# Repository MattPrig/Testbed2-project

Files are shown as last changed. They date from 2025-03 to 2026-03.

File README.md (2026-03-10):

# 🤖 Variable Mechanical Stiffness Robotics Arm - Testbed 2

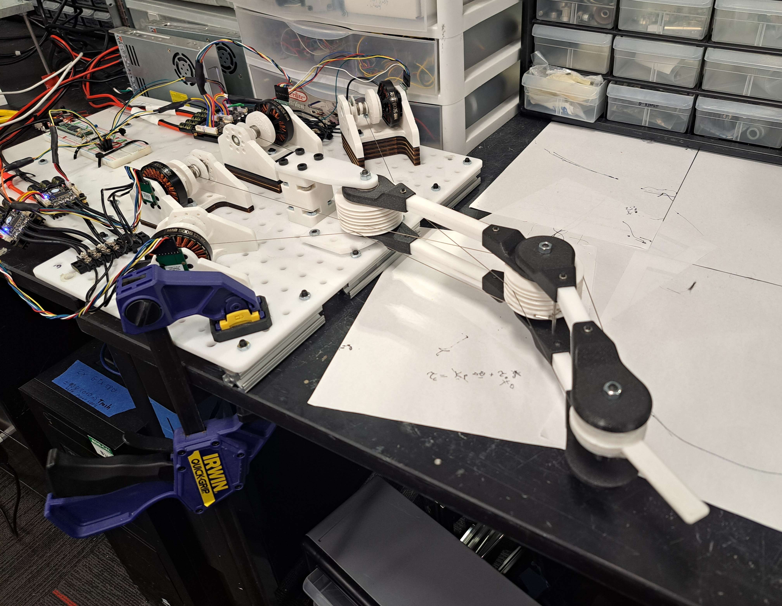
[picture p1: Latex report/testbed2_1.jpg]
Testbed Overview


## 🌟 Overview
This repository documents the development, construction, and testing of **Testbed 2**, a variable mechanical stiffness robotic arm. Built by **Matthieu Prigent** during it's internship in Salisbury Robotic Lab at Stanford, this prototype serves as a learning platform for the development of tendon-driven actuation and variable impedance control.

> [!NOTE]
> For a comprehensive technical analysis, please refer to the [Testbed 2 report.pdf](./Testbed%202%20report.pdf) located in the project root.

---

## 🛠️ System Architecture

### 🦴 Mechanical Design
The arm features a **tendon-driven system** with 3 joints controlled by 4 motors.
- **Cable Routing**: Designed for high symmetry to simplify control implementation.
- **Construction**: 3D printed PLA, lasercut Delrin, and Plexiglas.
- **Pulleys**: Sized to achieve a target force of ~16N at the end effector.
- **Interactive CAD**: The Onshape model can be accessed [here](https://cad.onshape.com/documents/c940a6fae7dfa620c9d885fc/w/fe90fad0bb4f54c2b765f4a7/e/dd32a71d364b7df9178d1a8b).

### ⚡ Electronics
A robust electronic backbone ensures high-speed control and communication:
- **MCU**: [Teensy 4.1](https://www.pjrc.com/store/teensy41.html) (Master controller).
- **Motor Drivers**: FLIPSKY Mini FSESC6.7 PRO (modified with $0.05\Omega$ resistors).
- **Motors**: 5008 EEE 170kV MAD brushless motors.
- **Sensors**: AS5048A magnetic absolute encoders.
- **Bus**: CAN bus for master-slave communication.

### 💻 Software Stack
- **Framework**: PlatformIO on VSCode.
- **Real-time Logic**: Based on the `TaskScheduler` library for deterministic execution.
- **FOC Control**: Utilizes the [SimpleFOC](https://docs.simplefoc.com/) library for precise torque and position control.
- **PC Interface**: Python-based GUI for real-time monitoring and control.

---

## 🕹️ Control Strategies

### 1. Torque Control
Implemented with a **coactivation** principle to maintain cable tension even when zero net torque is applied to the joints.

### 2. Position Control
A PD control loop in the joint space ($\theta$ space), allowing for stiff or compliant behavior by tuning $K_p$ and $K_d$ values.

### 3. Cartesian Control
Inverse kinematics implemented for the first two joints, allowing the end effector to follow lines or reach specific points in a 2D plane.

---

## 🔬 Anticogging Project
A specialized effort was made to mitigate **cogging torque**—the parasitic magnetic friction in brushless motors.
- **Status**: Captured cogging patterns using Fourier analysis (identifying 14Hz and 112Hz harmonics).
- **Location**: See the `anticogging project` directory for data collection scripts and analysis.

---

## 📂 Repository Structure
```text
.
├── anticogging project   # Scripts and data for cogging mitigation
├── Latex report         # Source files and images for the technical report
├── Testbed 2 report.pdf  # Final compiled report
└── Testbed2 code         # Source code for Teensy and Motor Drivers
    ├── Drivers code      # SimpleFOC implementation for drivers
    ├── Positioncontrolmaster # Teensy code for position control
    └── Torquecontrolmaster   # Teensy code for torque control
```

---

## 🚀 Future Improvements for Testbed 3
- [ ] **Structural Rigidity**: Link the top and bottom of the arm; use aluminum for load-bearing parts.
- [ ] **Cable Management**: Switch to spiral drums and Dyneema cables to reduce wear.
- [ ] **Electronics**: Switch to ODrive S1 drivers for native anticogging and better reliability.
- [ ] **Automation**: Fully implement absolute encoder sensing for the anticogging startup.

---
**Author**: Matthieu Prigent  
**Contact**: [matthieu.prigent@student-cs.fr](mailto:matthieu.prigent@student-cs.fr)

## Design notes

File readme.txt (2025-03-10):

This repo is to be used on the Testbed 2 prototype of the variable impedance actuator project.

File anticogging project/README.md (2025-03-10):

This whole project was to try to implement an anticogging feature to a brushless motor, to be used in robotic actuation with low gear reduction ratio.
It's still a bit messy as the data needs by hand post-processing, but the idea is to collect datas on currents used by the motor at every angle, use these datas to generate a lookup table of the compensation needed for cogging, and then use this lookup table of course.
I tried two current sensing methods, one measuring the direct DC current into the system at every angle, and another using the "virtual" Qcurrent from Field-Oriented Control processing.

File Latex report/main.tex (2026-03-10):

\documentclass{article}

% Language setting
% Replace `english' with e.g. `spanish' to change the document language
\usepackage[english]{babel}

% Set page size and margins
% Replace `letterpaper' with `a4paper' for UK/EU standard size
\usepackage[letterpaper,top=2cm,bottom=2cm,left=3cm,right=3cm,marginparwidth=1.75cm]{geometry}

% Useful packages
\usepackage{amsmath}
\usepackage{graphicx}
\usepackage{textalpha}
\usepackage{float}
\usepackage[colorlinks=true, allcolors=blue]{hyperref}

\title{Variable mechanical stiffness robotics arm testbed}
\author{Matthieu Prigent}

\begin{document}
\maketitle

\begin{abstract}
This document aims to summarize what was done in the development and building of testbed 2, and what was learned from it, for further development with testbed 3.
\end{abstract}

\begin{figure}[H]
\centering

\end{figure}

\newpage
\tableofcontents
\newpage

\section{Introduction}

This document aims to summarize what was done in the development and building of testbed 2, and what was learned from it, for further development with testbed 3. All of the documents related with this report, which include the software for running the arm and the can be found on this git repo and this drive. The Onshape model can be found \href{https://cad.onshape.com/documents/c940a6fae7dfa620c9d885fc/w/fe90fad0bb4f54c2b765f4a7/e/dd32a71d364b7df9178d1a8b}{here}.

\begin{figure}[H]
\centering
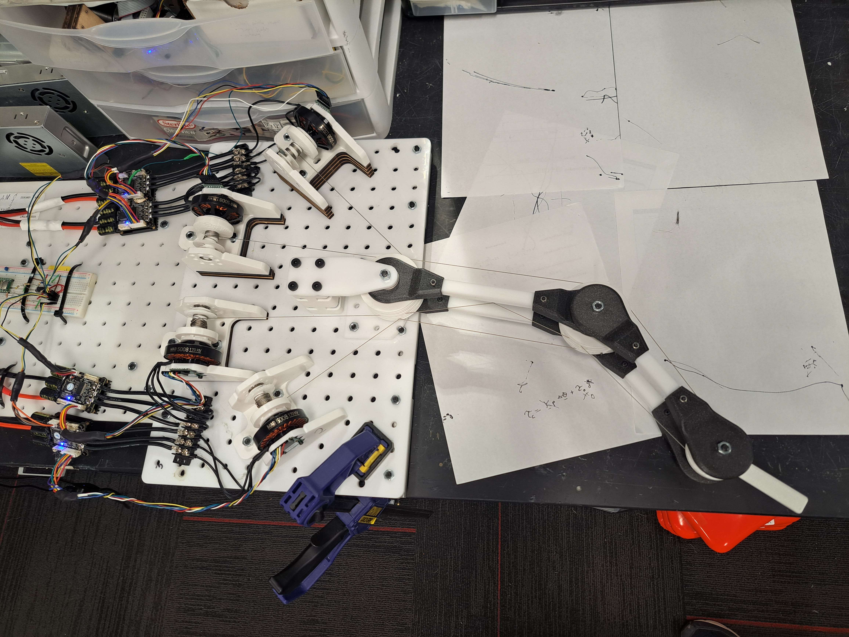
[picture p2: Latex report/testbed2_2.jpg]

\caption{\label{fig:overview}Overview of the testbed.}
\end{figure}

On the previous figure \ref{fig:overview}, we can see the testbed, with the main micro controller (partially cut on it) on  the far left, then the 4 motor drivers linked throught the CAN bus, the 4 motor pods, and then the arm with its 3 joints.

\section{Mechanical design}

\subsection{cable routing}

\begin{figure}[H]
\centering
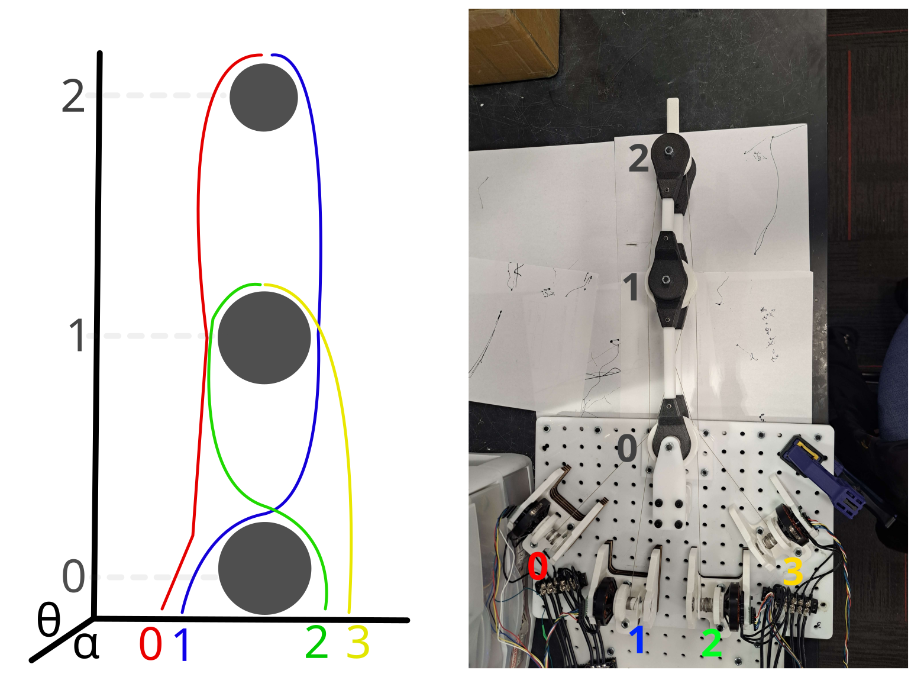
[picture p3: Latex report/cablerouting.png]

\caption{\label{fig:cablerouting}Routing of the cables in the arm.}
\end{figure}

The routing of the cables is done as shown on \ref{fig:cablerouting}. This geometry was choose for it's high degree of symmetry and hence easier control implementation features. We call the angle of each of the motors that are pulling a cable \textalpha, going from 0 to 3. We call the angle of each of the joints from the arm \texttheta, going from 0 to 2. On the actual arm, the cable linked to the motor 0 is on the top pulleys, while the cable linked to the motor 3 is on the bottom pulley. Based on \ref{fig:cablerouting}, we get that the matrix of the direction of the arm, going from \textalpha to \texttheta, is :

\begin{align}
P_{0} = \begin{pmatrix}
1 & 1 & -1 & -1 \\
1 & -1 & 1 & -1 \\
1 & -1 & 0 & 0 
\end{pmatrix}
\end{align}

Now, taking into account the diameter of the pulleys, calling $d_{m}$ the diameter of the motor pulleys and $D_{0}$, $D_{1}$ and $D_{2}$ the respective diameter of the 3 joints, we can rewrite the matrix while taking into account the reduction ratio :

\begin{align}
P = d_m \begin{pmatrix}
\frac{1}{D_{0}} & \frac{1}{D_{0}}  & -\frac{1}{D_{0}}  & -\frac{1}{D_{0}}  \\
\frac{1}{D_{1}} & -\frac{1}{D_{1}} & \frac{1}{D_{1}} & -\frac{1}{D_{1}} \\
\frac{1}{D_{2}} & -\frac{1}{D_{2}} & 0 & 0 
\end{pmatrix}
\end{align}

\subsection{sizing of the arm}

\begin{figure}[H]
\centering
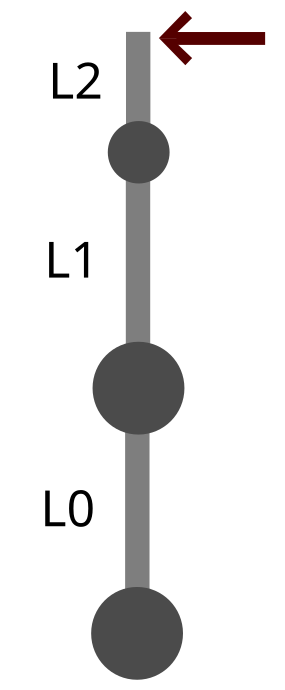
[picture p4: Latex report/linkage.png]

\caption{\label{fig:linkage}Size of the different links of the arm, and direction of the desired force capability of the arm.}
\end{figure}

To get a certain area for the arm the be able to reach, we arbitrary choose the length of the links so that the arm is about ~45cm long. We will name the length of the links $L_{0}$, $L_{1}$ and $L_{2}$. get a certain force capability $F$ at the output of the arm, we need to size the pulleys accordingly, knowing the defined length. We will name the torque capabilities of each joint $\tau_{0}$, $\tau_{1}$ and $\tau_{2}$. Finally, the torque of the motors will be named $\tau_{mi}$.
\\
First, we can write relation between $\tau_{mi}$ and the $\tau_{i}$.

\begin{align}
\frac{1}{d_{m}}
\begin{pmatrix}
D_{0} & D_{0} & -D_{0} & -D_{0}\\
0 & 0 & D_{1} & -D_{1}\\
D_{2} & -D_{2} & 0 & 0\\
\end{pmatrix}
\begin{pmatrix}
\tau_{m0} \\
\tau_{m1} \\
\tau_{m2} \\
\tau_{m3}
\end{pmatrix}
=\begin{pmatrix}
\tau_{0} \\
\tau_{1} \\
\tau_{2}
\end{pmatrix}
\end{align}

We can see a major difference between this matrix and the kinematics matrix seen above, which is that the motors 0 and 1 do moves when the second joint is rotated, but do not contribute to the torque on the second joint. This result is quiet unintuitive, but can be verified experimentally on the testbed.
To get the maximum torque of each joint, we use this relation and specify that the motors pulling in the desired direction are at $\tau_{mmax}$, and the ones from the other side are at the base co-activation $\tau_{mmin}$.

\begin{align}
\frac{2D_0}{d_m}(\tau_{mmax}-\tau_{mmin}) = \tau_{0} \\
\frac{D_1}{d_m}(\tau_{mmax}-\tau_{mmin}) = \tau_{1} \\
\frac{D_2}{d_m}(\tau_{mmax}-\tau_{mmin}) = \tau_{2}
\end{align}

Which, making the hypothesis that the co-activation is small compared to $\tau_{mmax}$ get us to :

\begin{align}
\frac{2D_0\tau_{mmax}}{d_m} = \tau_{0} \\
\frac{D_1\tau_{mmax}}{d_m} = \tau_{1} \\
\frac{D_2\tau_{mmax}}{d_m} = \tau_{2}
\end{align}

We need, if we desire to keep the arm in an equilibrium, to verify 

\begin{align}
F = \frac{\tau_{2}}{L_{2}} = \frac{\tau_{1}}{L_{2}+L_{1}} = \frac{\tau_{0}}{L_{2}+L_{1}+L_{0}}
\end{align}

Combining these equations and the precedent reasoning on the arm, we finally get that the diameters of the pulleys must verify :

\begin{align}
D_2 &= \frac{F d_mL_{2}}{ \tau_{mmax}} \\
D_1 &= \frac{F d_m(L_{2}+L_{1})}{ \tau_{mmax}} \\
D_0 &= \frac{F d_m(L_{2}+L_{1}+L_{0})}{2 \tau_{mmax}}
\end{align}

And we see that all of the 3 pulleys are proportional to the diameter of the motor pulleys. The motor pulleys diameter can be choose arbitrarily, but its final value will change the tension of the cables. Bigger motor pulleys will mean relieving the cables from some stress, but also that the value of the $D_{i}$ will be bigger, which can be inconvenient for the size of the arm. The final choice was to made these pulley quiet small.

\vspace{0.5cm}
Now we know that $\tau_{mmax}$ is about 1N.m for a motor, that $L_0=21cm$, $L_1=16cm$, $L_2=9cm$ and that $d_m=1.4cm$.
The target force that we want is about 16N of force. We could go for a bigger force and hence reduction ratio, but that would lead to a high refleted inertia of the motor to the arm). With all of that, we get that $D_2 = 2cm$, $D_1=5.6cm$ and $D_0=5.2cm$. These value were in the end rounded to $D_2 = 3cm$, $D_1=6cm$ and $D_0=6cm$, ensuring that we get the desired force capability.

\subsection{Building of the testbed}
The testbed was designed entirely on Onshape, the project can be found \href{https://cad.onshape.com/documents/c940a6fae7dfa620c9d885fc/w/fe90fad0bb4f54c2b765f4a7/e/dd32a71d364b7df9178d1a8b}{here}.
The testbed was build using mostly 3D printed PLA, and lasercutting of Delrin and Plexiglas for some parts (using the laser cutter from lab64). This was because of the convenience of using already mastered tools for me, instead of going for more rigid aluminum. I would say it's fine for what we are doing with this testbed right now.

\begin{figure}[H]
\centering
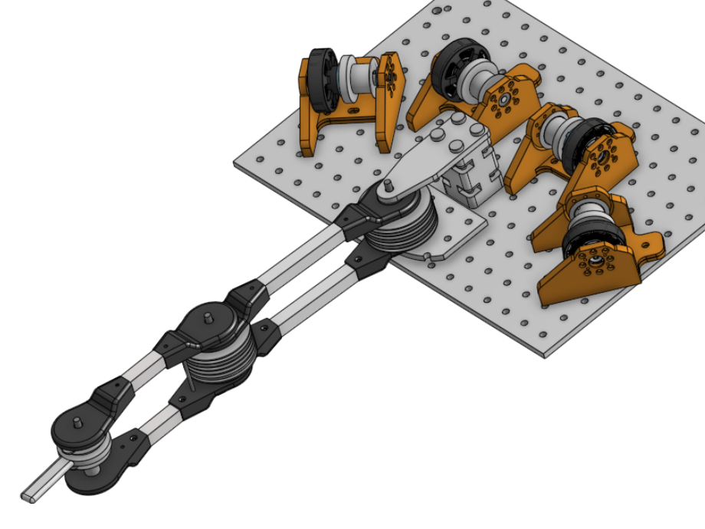
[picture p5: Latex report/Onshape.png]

\caption{\label{fig:Onshape}Onshape model.}
\end{figure}

\subsection{What to improve mechanically for testbed 3}

\begin{itemize}
\item Design a structural link between the top and the bottom part of the arm to improve it's rigidity by a lot (see the blue lines on \ref{fig:pulleysideview}).
\item Switch to aluminum for parts that handle a lot of load and can bend due to it (You can use sendcutsend or JLCCNC for machining them if necessary, it is not that expensive if the part is designed properly). Some of the parts that were bending a lot were especially on the motor side, like the main plate that was made out of flexible Plexiglas, and the motor pulley as well. For the motor pulley, putting a Dowel pin in it may do the trick for making it more rigid.
\item Switch to a spiral drum and spiral pulleys to prevent cables from ripping against each other. The current smooth pulleys and drums lead to some undesired behaviors, long term tear off of the cable and awful noises. This may be a not so good idea if the arm pulleys ends up being taller, making the arm too tall compared to its width.
\item switch from steel cables to dyneema cable.
\item We can merge two of the pulleys from the second joint (the ones circled in red on \ref{fig:pulleysideview}) into one, as their movement are already linked anyway. This reduce the part count and complexity of the arm by a bit. What to get from this is that one pulley per cable is not necessary if adjacent pulleys ends up having a linked rotation in the same direction anyway.
\end{itemize}

The next mechanical challenges to solve on testbed 3 nest in how to run the cables in a non-planar arm.

\begin{figure}[H]
\centering
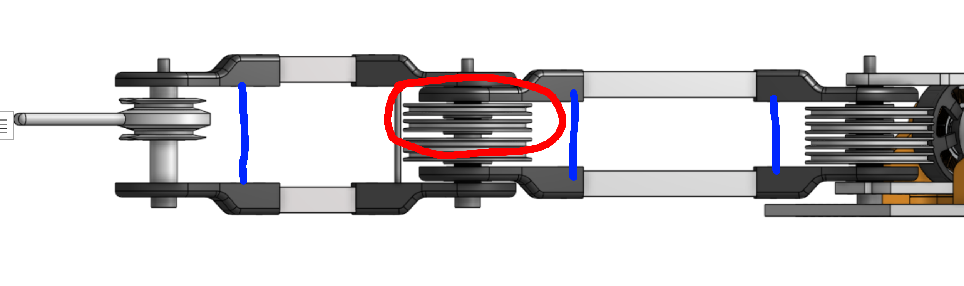
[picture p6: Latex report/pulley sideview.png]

\caption{\label{fig:pulleysideview}Sideview of the arm on Onshape.}
\end{figure}

\begin{figure}[H]
\centering
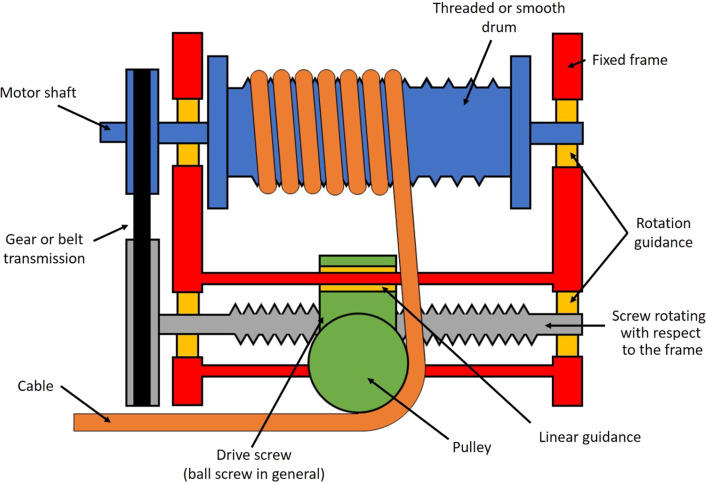
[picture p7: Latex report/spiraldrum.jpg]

\caption{\label{fig:spiraldrum}An example of an interesting way to make a spiral drum. Doing it this way can also enable a permanent pretensioning of the cables by adding a spring in the system.}
\end{figure}

\section{Electrical design}

\subsection{General architecture}

\begin{figure}[H]
\centering
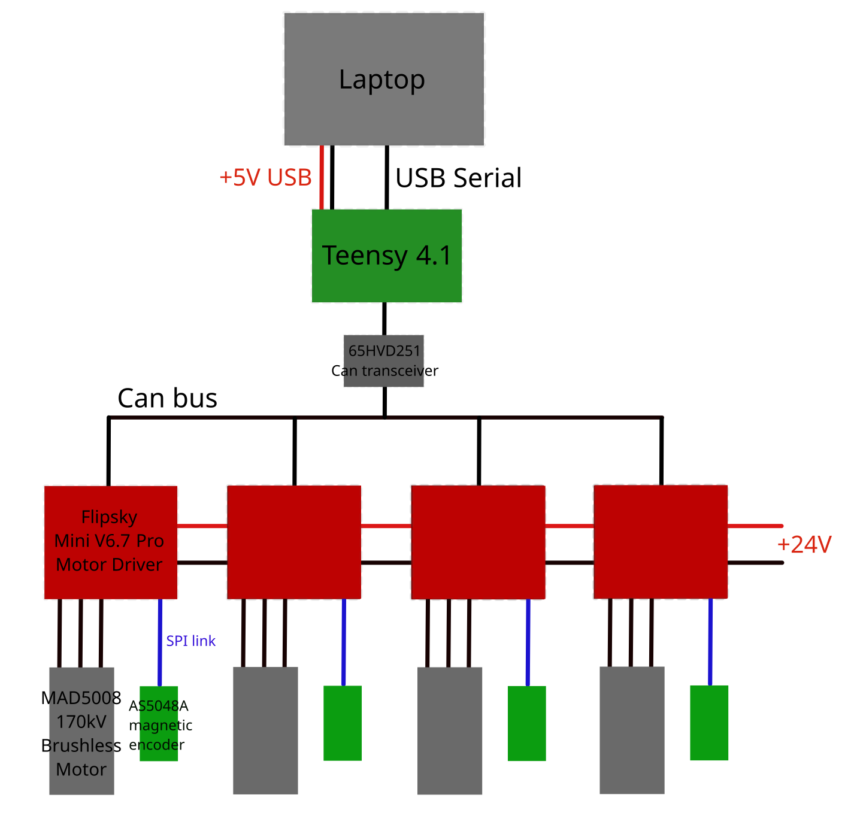
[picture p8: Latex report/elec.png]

\caption{\label{fig:elec}Architecture of the electronics of the arm.}
\end{figure}

To power on the testbed, you need to plug in the two 24V power supplies that power the motor drivers, and then plug in the usb cable coming from the Teensy to your computer.

\subsection{references of the components}

\begin{itemize}
    \item \href{https://www.pjrc.com/store/teensy41.html}{Teensy 4.1} (a great and powerful microcontroller)
    \item \href{https://www.digikey.com/en/products/detail/texas-instruments/SN65HVD251P/948551}{SN65HVD251 Can tranceiver}
    \item \href{https://flipsky.net/products/mini-fsesc6-7-pro-70a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}{FLIPSKY Mini FSESC6.7 PRO motor driver}
    \item \href{https://mad-motor.com/products/mad-components-5008-eee?VariantsId=10441}{5008 EEE 170kV MAD brushless motor}
    \item \href{https://www.digikey.com/en/products/detail/ams-osram-usa-inc/AS5048A-ADAPTERBOARD/3188612}{AS5048A magnetic encoder}
\end{itemize}

\subsection{The motor drivers}

One of the main wrong choice that was made was to use Flipsky motor drivers (that are originally meant for powering skateboard motors). They indeed can drive brushless motors with field-oriented control, but this choice led to needing to change the resistors on the motor drivers, and unsoldering them is a painful process to do (and is risky for the driver, you can damage it doing so). For better current capabilities, it was needed to switch from $0.005\Omega$ resistors to $0.05\Omega$ ones.

\begin{figure}[H]
\centering
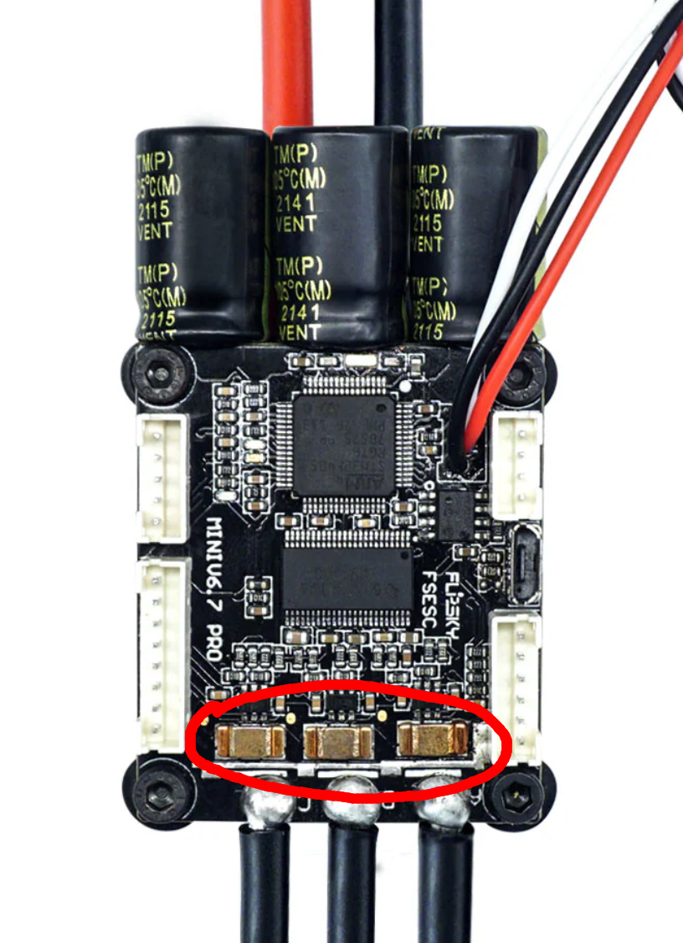
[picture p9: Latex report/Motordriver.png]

\caption{\label{fig:motordriver}The motor driver, with the resistors circled in red.}
\end{figure}

\subsection{Electrical tips for testbed 3}
\begin{itemize}
\item To get a better data rate and less interruption during the control loop due to Serial transmission to the laptop (which is quiet slow), it may be interesting to buy a CAN to USB module to make the laptop communicate directly throught the CAN bus, enabling us to get much more data in real time. It may also introduce more complexity in terms of coding, so I'm not totally sure about the pertinence of doing it for now.
\item for discussion about choosing a new motor driver and new motor, see the chapter on Cogging.
\end{itemize}
\newpage
\section{Software}

The framework used for the development this testbed software was PlatformIO on VSCode. I recommend finding a quick tutorial on it to learn about it, how to upload a code, look at the Serial Monitor, ect...
You also need Python for the computer interface.
The current code is made so that you can extend it as much as you like for high number of degrees of freedom, as long as you take the time to write down the invert kinematics matrix, and change the Controlloopcallback function. This should enable a rapid iteration on the code for the next testbed.
\\
\vspace{0.1cm}

To upload a new code on the Teensy 4.1, you can directly plug it to your computer with a micro-USB cable. For the motor drivers, it's a little trickier, as you need to use an external JTAG uploader. The one that we're using is the one from the white nucleo board on \ref{fig:nucleoboard}. To plug it to a motor driver, just plug the 5-pins cables to the motor driver. You can then upload a new code to the motor driver throught it. One thing to take care of when doing so is to change the CAN address of the driver written in the code to the corresponding one (the number of the motor, from 0 to 3, being the CAN address of the motor driver you are uploading to).
\\

Reading this, you should have understand that the software from the testbed is made of two main parts : the code for the Teensy main micro controller, and the code for all of the drivers.

\begin{figure}[H]
\centering
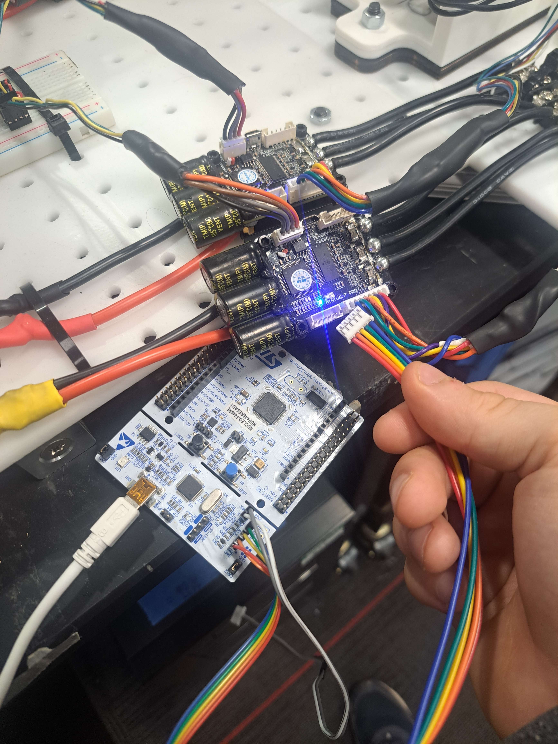
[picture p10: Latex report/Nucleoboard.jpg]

\caption{\label{fig:nucleoboard}The 5 pins connector to plug and the white nucleo board.}
\end{figure}

\subsection{Teensy code}

\subsubsection{TaskScheduler}

The main code running on the Teensy is heavily based on the TaskScheduler library. This library allows us to specify a frequency for the execution of several functions in a simple and readable way, as long as the micro controller has the processing power to respect the specified timings.

\begin{figure}[H]
\centering
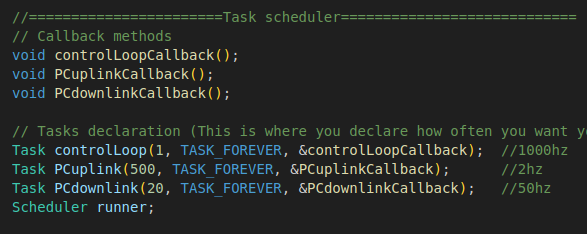
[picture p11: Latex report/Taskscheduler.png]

\caption{\label{fig:tasksched}The task scheduler functions declaration.}
\end{figure}

We call the functions that we want to call "Callback", and in the Task declaration we specify the delay to happen between each execution of the function. For example, the controlLoop is called once every millisecond, the PCuplink once every 500ms and the PCdownlink once every 20ms (equivalent to 1000Hz for the controlloop, 2Hz for sending back monitoring datas to the PC and 50Hz for processing messages incoming from the PC).

\subsubsection{CAN bus and objects}

Another main point of this code is how to the CAN bus is managed. It's managed using objects named FOCDriver that are the image of the motors drivers from the Teensy point of view. The Teensy is the master of the CAN bus, starting every communication on it. It can either use a set method to send a value to one of the driver to be set on it, or a get method that asks for an update of a value that is currently stored in the object.
\\
In the driver code, a Controller object is the image of the Teensy, and it handles the reception of these set and update, and in the case of the later send back the requested value.
\\
One the drawback of the way the CAN bus is managed is that you need to call processCANMessages that manage the reading of the incoming message often to ensure that any received new information is handled as soon as possible. In reality it could be improved if you call the function only when you know that there should be a new CAN message (because the Teensy initiate any CAN communication, you're able to predict when a new message should be there). But I didn't did it and instead decided to call calling the processCANMessages often in the different functions. It works so why changing it.

\subsection{Driver code}

The driver code essentially execute a FOC-oriented control algorithm on the motor driver. The principle of FOC is, using the phase currents and the position of the motor, to enable precise torque control of the motor. For that, we're using the \href{https://docs.simplefoc.com/}{SimpleFOC} library that I recommend you to read the documentation.

\begin{figure}[H]
\centering
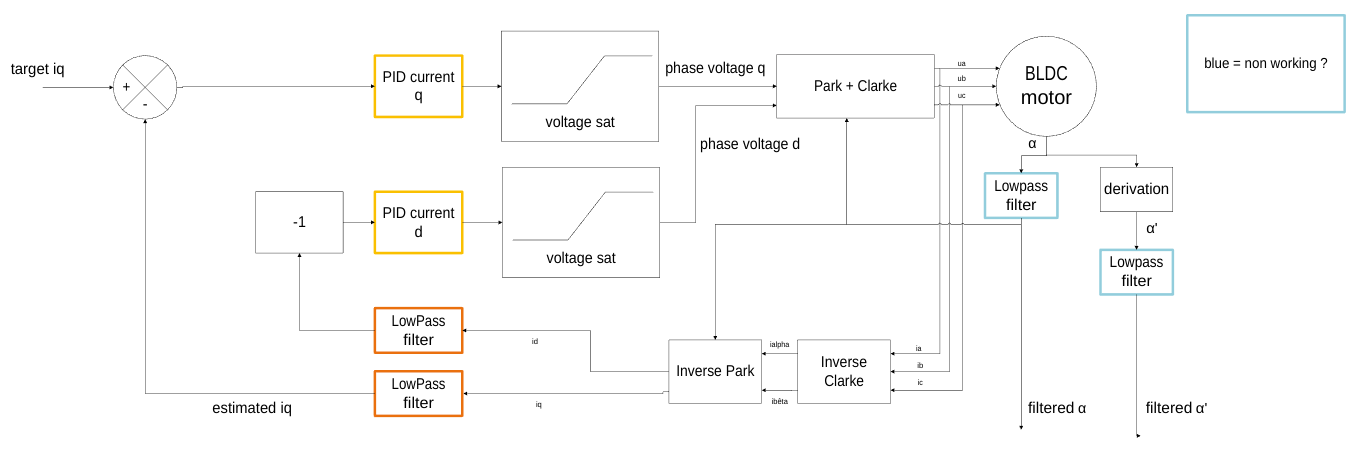
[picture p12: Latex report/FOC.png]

\caption{\label{fig:FOC}The FOC algorithm executed on the driver.}
\end{figure}

\newpage
\section{Control}

All the $\theta$ are 3-dimensional vectors in the joint space, and all of the $\alpha$ are 4-dimensional vectors in the motor space. Iq is 4-dimensional as well, and is actually named targetforce in the code.

\subsection{Torque control}

\begin{figure}[H]
\centering

\caption{\label{fig:torquecontrol}The torque control algorithm executed on the Teensy}
\end{figure}

The torque control algorithm is quiet straigthforward, with one subtility being the way the coactivation is calculated. The principle of the coactivation is to look which motor has the minimal torque that will be applied to it (which is generally negative) and to increase it until this particular motor has a minimalforce applied it so it keeps the cables tensioned. You then also increase the force applied by all the other motors by the same amount, so that there's no bias in the output torque of the arm.
\\
The current Python interface of the torque control algorithm is a small interface with 4 sliders to command the torque of the 3 arm joints + the coactivation. A cool demo to do with this code is simply to let the torque to be 0 on all of the joints and move the arm freely by hand, while all of the cables stay tensionate, you can quiet feel the motor through the transmission.
\vspace{0.1cm}
\\
The jointtomotor function is the following matrix product : 

\begin{align}
P = d_m \begin{pmatrix}
\frac{1}{D_{0}} & \frac{1}{D_{1}}  & \frac{1}{D_{2}} \\
\frac{1}{D_{0}} & -\frac{1}{D_{1}} & -\frac{1}{D_{2}} \\
-\frac{1}{D_{0}} & \frac{1}{D_{1}} & 0 \\
-\frac{1}{D_{0}} & -\frac{1}{D_{1}} & 0 \\
\end{pmatrix}
\begin{pmatrix}
\tau_{0} \\
\tau_{1} \\
\tau_{2}
\end{pmatrix}
=\begin{pmatrix}
\tau_{m0} \\
\tau_{m1} \\
\tau_{m2} \\
\tau_{m3}
\end{pmatrix}
\end{align}

\subsection{Position control}

\begin{figure}[H]
\centering
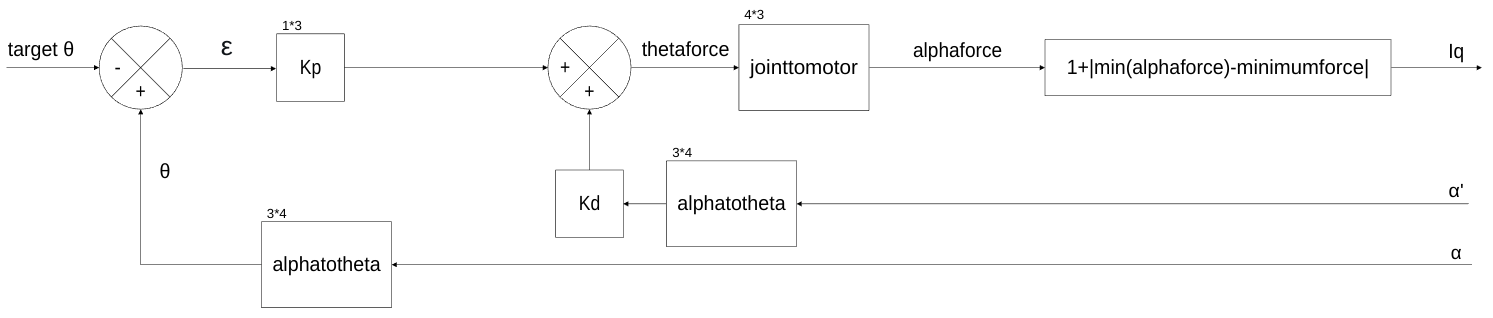
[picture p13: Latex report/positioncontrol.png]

\caption{\label{fig:poscontrol}The position control algorithm executed on the Teensy}
\end{figure}

The position control loop reuse the torque control algorithm and use the position and speed measurements made on each of the motors to implement a PD control loop, in $\theta$ space. There is thus 3 Kp and 3 Kd values, one for each joint. Their current values were roughly choose at the end of my stay in the lab and could be finetuned, first by being leveled so that the joint-to-joint transmission feel more natural, and then by being increased or decreased so that the arm is either stiffer or more compliant.

The alphatotheta function is the following matrix product : 

\begin{align}
P =  \begin{pmatrix}
\frac{d_m}{4D_0} & \frac{d_m}{4D_0} & -\frac{d_m}{4D_0} & -\frac{d_m}{4D_0} \\
0 & 0 & \frac{d_m}{2D_1} & -\frac{d_m}{2D_1} \\
\frac{d_m}{2D_2} & -\frac{d_m}{2D_2} & -\frac{d_m}{D_1} & \frac{d_m}{D_1} \\
\end{pmatrix}
\begin{pmatrix}
\tau_{m0} \\
\tau_{m1} \\
\tau_{m2} \\
\tau_{m3}
\end{pmatrix}
=\begin{pmatrix}
\tau_{0} \\
\tau_{1} \\
\tau_{2}
\end{pmatrix}
\end{align}

For the Python interface of this mode, there's 2 that are available. The first one is the Jointpositioncontrol one, that simply enable to move the joints with 3 sliders. It is quiet intuitive to use.
\vspace{0.1cm}
\\
The second one is a code that show the reachable surface by the third joint of the arm. You then click on one point of this space, and the arm will reach this new cartesian position from it's precedent position while following a line. This code only uses the two first joint, the third being let free because otherwise there would be an infinite number of solutions for the joints of the arm. Because there is still two possible theta solutions for each of the cartesian position of the arm with two joints, I decided to split the reachable surface of the arm into two halves, each half having one conformation enabled. If you switch from one half to the other, the arm will go back being straight before switching to the other half.
\vspace{0.1cm}
\\
Right now, the dynamics of the arm are not taken into account when driving the arm, which makes the arm move sometimes faster or slower than expected for some joints, and prevents the arm from actually following a line. This could be worked out in the future by a more sophisticated control loop, or by tuning the Kp values.

\subsection{Future works to be done}

One of the future work to be done with Testbed 2 in terms of control and sensing may be to use the position control mode, with the Kp of the last joint set to 0 and to look at the position of the end effector and use it as a way to "sense" and map the environnement that Testbed 2 is evolving in. Using torque control to press gently and precisely on a defined surface could also be something to try out.

\newpage
\section{Cogging}

\subsection{My work}

Most of the files for this study can be find in the Git repo in the "anticogging project" folder.

\begin{figure}[H]
\centering
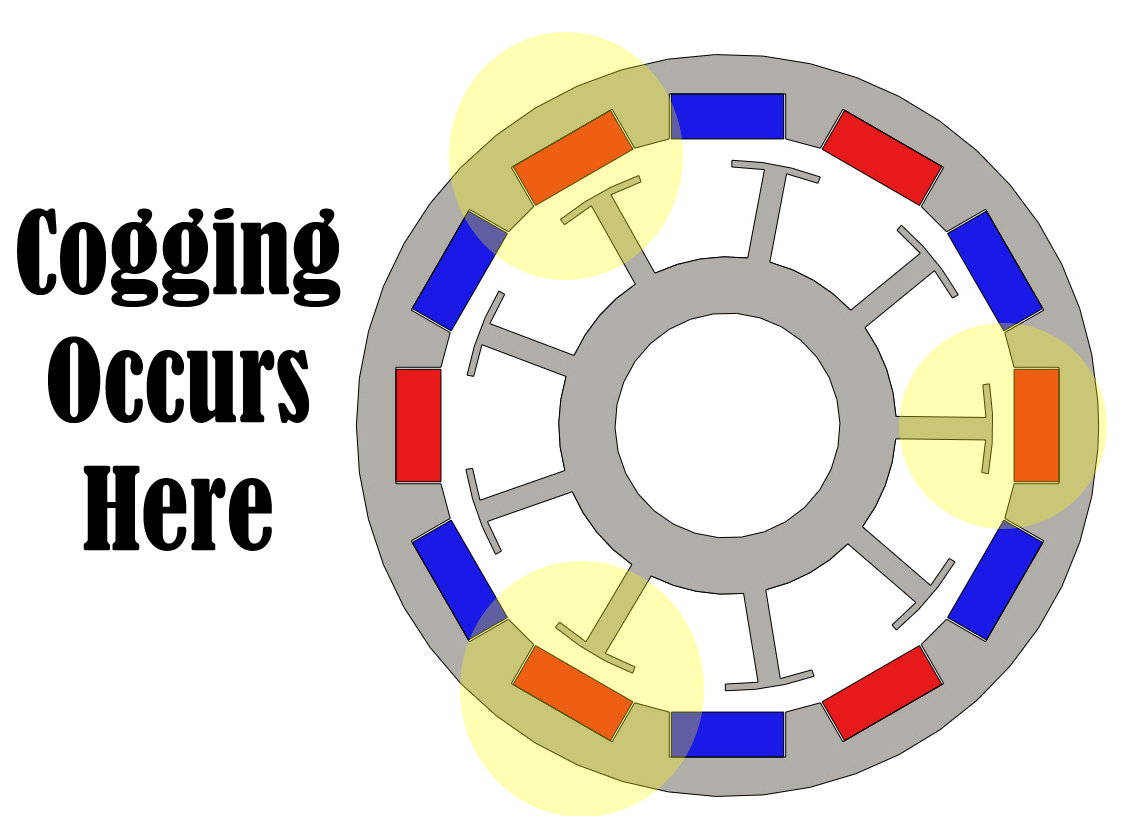
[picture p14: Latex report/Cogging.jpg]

\caption{\label{fig:cogging}}
\end{figure}

Cogging is the parasitic torque caused by the interaction between the metallic stator of a motor and the magnets from the rotor. Unfortunately, it is quiet high on our current motors, and create two issues : 
- It makes us feel small "bumps" and inconsistency in the movement and torque of the arm, due to these variations in torque depending on the position of the motor.
-High "deadband" for the motors and hence the arm : the cogging can be assimilated to a sort of high static magnetic friction, that prevent the motor from going to a precise position (high steady state error) when using a PD control loop. (Using integral control solve this issue, but also ruins the compliance of the arm).

\begin{figure}[H]
\centering
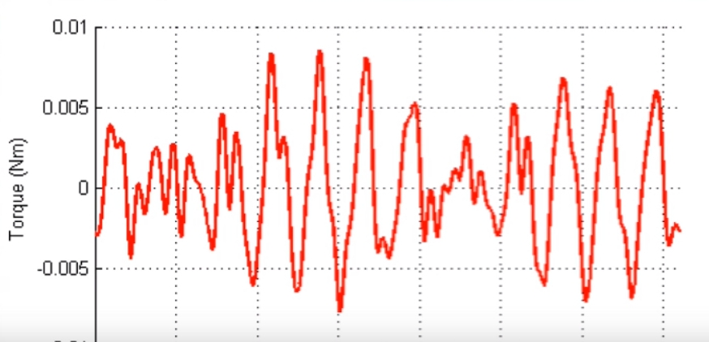
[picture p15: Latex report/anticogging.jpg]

\caption{\label{fig:anticogging}An example of the pattern of the cogging of a motor.}
\end{figure}

What I first did was to map the cogging using position control, and looking at the current used by the motor to hold a given position, I was able to get the cogging torque at this particular position. A Fourier analysis of the obtained data told me that our motor had two main frequency for cogging : 14Hz and 112Hz.
\vspace{0.1cm}
\\
This can be explained easily if we take a look at the geometry of a brushless motor. A brushless motor has slots, which are the branches of the stator, and poles pairs, which are the pairs of magnets on the rotor. Our motor has 24 slots and 14 pole pairs (28 magnets). The 14Hz is hence easy to understand, and 112Hz = 28*8Hz, Thus an harmonic of the geometry.
\vspace{0.1cm}
\\
Using the obtained datas, I set up a feed-forward in the control loop adding the opposite of the cogging into the control. Unfortunately, I was stupid at the time, thinking that the magnetic encoders were relative encoders, which was an issue for the start-up of the anticogging algorithm (because the cogging is dependant of the position of the motor obviously). These encoders are actually absolute encoder. So I tried to make the anticogging algorithm to start blindly at a local minimum, without really knowing where the motor was in the cogging pattern. This led to deceptive result.

\subsection{giving it another shot}

I wish I gave anticogging a better shot, several months later. Now that we know that the magnetic encoders are absolute, doing it should be quiet simpler. If someone want to try it again, the best ressources on it are \href{https://journals.sagepub.com/doi/full/10.1177/0278364915599045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}{this paper} from Matthew Piccoli and Mark Yim, as well as the SimpleFOC discord, where there is a bunch of people that already tried to implement anticogging with different level of success.

\subsection{The future for motor drivers and motors}

If you decide on continuing using brushless motors, you can switch to \href{https://shop.odriverobotics.com/collections/motor-controllers/products/odrive-s1}{Odrives} motor drivers. Firstly, this way you won't need to switch the resistors each time. Secondly, the Odrives comes with a proprietary software (that you still can replace by SimpleFOC is you end up not wanting to use it). This software have an \href{https://docs.odriverobotics.com/v/latest/guides/anticogging.html}{anticogging algorithm} implemented, it could be interesting giving it a try before giving up on brushless motors.
\vspace{0.1cm}
Finally, we need to discuss about the motor. Switching to even larger outrunner brushless motor with less cogging and higher torque (low Kv number) (we will eventually need more torque if we want a bigger arm anyway). I personally would have loved to try the \href{https://www.aliexpress.us/item/3256807604192884.html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}{Eaglepower LA8308} based on their online reputation in robotics.
\\
Otherwise, following Ken advice and switch to brushed motors may be the wisest choice, if the next person handling the project feels confident doing the switch to this type of motors.

\section{Conclusion}
To get a detailled conclusion on the learnings for each part of Testbed 2, read the end of each chapter, where there is different recommandation based on my experience with it. I don't know what is the next step for Testbed 2, apart for some control/sensing experiments to run on it. If you need any additional information/clarification on Testbed 2, you can reach me at \href{mailto:matthieu.prigent@student-cs.fr}{matthieu.prigent@student-cs.fr} .
\end{document}

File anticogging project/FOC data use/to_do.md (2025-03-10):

- [x] length of messages
- [x] harmonisation of function names
- [x] serial length
- [x] beta sensor
- [x] beta communication
- [x] alpha communication
- [x] stiffness curve
- [ ] (change springs)
- [ ] (velocities implementation)
- [x] improve startup sequence
- [ ] refactor debug messages
- [ ] send errors trough CAN
- [x] use beta sensors for control
- [ ] use stiffness curve for control

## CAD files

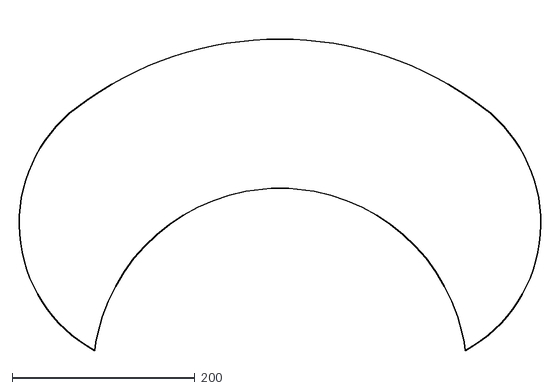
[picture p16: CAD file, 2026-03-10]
Testbed2 code/Positioncontrolmaster/armreach.dxf
578.0 x 366.0

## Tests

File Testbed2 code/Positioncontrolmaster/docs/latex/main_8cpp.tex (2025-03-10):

\doxysection{src/main.cpp File Reference}
\hypertarget{main_8cpp}{}\label{main_8cpp}\index{src/main.cpp@{src/main.cpp}}
{\ttfamily \#include $<$Arduino.\+h$>$}\newline
{\ttfamily \#include $<$ACAN\+\_\+\+T4.\+h$>$}\newline
{\ttfamily \#include "{}FOCDriver.\+h"{}}\newline
\doxysubsubsection*{Functions}
\begin{DoxyCompactItemize}
\item 
bool \mbox{\hyperlink{main_8cpp_ace64893cc25018d118abec238729ff05}{init\+\_\+\+CAN}} (int baudrate=1000 \texorpdfstring{$\ast$}{*}1000, bool print\+\_\+params=true)
\item 
void \mbox{\hyperlink{main_8cpp_a4fc01d736fe50cf5b977f755b675f11d}{setup}} ()
\item 
void \mbox{\hyperlink{main_8cpp_afe461d27b9c48d5921c00d521181f12f}{loop}} ()
\end{DoxyCompactItemize}

\doxysubsection{Function Documentation}
\Hypertarget{main_8cpp_ace64893cc25018d118abec238729ff05}\index{main.cpp@{main.cpp}!init\_CAN@{init\_CAN}}
\index{init\_CAN@{init\_CAN}!main.cpp@{main.cpp}}
\doxysubsubsection{\texorpdfstring{init\_CAN()}{init\_CAN()}}
{\footnotesize\ttfamily \label{main_8cpp_ace64893cc25018d118abec238729ff05} 
bool init\+\_\+\+CAN (\begin{DoxyParamCaption}\item[{int}]{baudrate}{ = {\ttfamily 1000\texorpdfstring{$\ast$}{*}1000}, }\item[{bool}]{print\+\_\+params}{ = {\ttfamily true}}\end{DoxyParamCaption})}

initialise the can 3 bus, checks for erros and prints the settings

\begin{DoxyParams}{Parameters}
{\em baudrate} & the baudrate of the can bus, default is 1Mbit/s \\
\hline
{\em print\+\_\+params} & if true, prints the settings of the can bus, default is true \\
\hline
\end{DoxyParams}
\begin{DoxyReturn}{Returns}
true if the can bus was initialised successfully
\end{DoxyReturn}
\Hypertarget{main_8cpp_afe461d27b9c48d5921c00d521181f12f}\index{main.cpp@{main.cpp}!loop@{loop}}
\index{loop@{loop}!main.cpp@{main.cpp}}
\doxysubsubsection{\texorpdfstring{loop()}{loop()}}
{\footnotesize\ttfamily \label{main_8cpp_afe461d27b9c48d5921c00d521181f12f} 
void loop (\begin{DoxyParamCaption}{}{}\end{DoxyParamCaption})}

\Hypertarget{main_8cpp_a4fc01d736fe50cf5b977f755b675f11d}\index{main.cpp@{main.cpp}!setup@{setup}}
\index{setup@{setup}!main.cpp@{main.cpp}}
\doxysubsubsection{\texorpdfstring{setup()}{setup()}}
{\footnotesize\ttfamily \label{main_8cpp_a4fc01d736fe50cf5b977f755b675f11d} 
void setup (\begin{DoxyParamCaption}{}{}\end{DoxyParamCaption})}

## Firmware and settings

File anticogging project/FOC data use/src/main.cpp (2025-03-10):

#include <Arduino.h>
#include <board_vesc_6.h>
#include <SimpleFOC.h>
//#include "STM32_CAN.h"
#include "communication.h"
#include "debug.h"


//STM32_CAN Can( CAN1, DEF );  //Use PA11/12 pins for CAN1.
//STM32_CAN Can( CAN1, ALT );  //Use PB8/9 pins for CAN1.
//STM32_CAN Can( CAN1, ALT_2 );  //Use PD0/1 pins for CAN1.
//STM32_CAN Can( CAN2, DEF );  //Use PB12/13 pins for CAN2.
//STM32_CAN Can( CAN2, ALT );  //Use PB5/6 pins for CAN2
//STM32_CAN Can( CAN3, DEF );  //Use PA8/15 pins for CAN3.
//STM32_CAN Can( CAN3, ALT );  //Use PB3/4 pins for CAN3

const int motorPolePairs = 14;


HardwareSerial Serial6(USART6);
Debug debug(&Serial6, DEBUG_WARNING);

Controller controller(&debug);

BLDCMotor motor = BLDCMotor(motorPolePairs);
BLDCDriver6PWM driver(H1, L1, H2, L2, H3, L3, EN_GATE);
InlineCurrentSense current_sense = InlineCurrentSense(0.005f, 20.0f, CURRENT_1, CURRENT_2, CURRENT_3);

MagneticSensorSPI sensorAlpha = MagneticSensorSPI(AS5048_SPI, SPI1_NSS);
MagneticSensorSPI sensorBeta = MagneticSensorSPI(AS5048_SPI, SPI1_NSS_2);

float target_current = 0.0;
unsigned long lastCommand = 0;

// instantiate the commander
Commander command = Commander(debug);
void doTarget(char* cmd) {
  command.scalar(&target_current, cmd);
  lastCommand = millis();
}





void setup() {

  controller.addMotor(&motor);
  //controller.addSensorBeta(&sensorBeta);

  motor.phase_resistance = 0.195; // [Ohm]
  //motor.voltage_limit = 0.5; // [V] - if phase
  motor.current_limit = 6;      // [Amps] - if phase resistance defined
  motor.velocity_limit = 10; // [rad/s] 5 rad/s cca 50rpm
  driver.pwm_frequency = 20000; //default is 25000Hz

  delay(1000);
  Serial6.begin(115200);
  delay(1000);
  Serial6.println("Motor ready!");
  motor.useMonitoring(debug);
  motor.monitor_downsample = 3000;
  //motor.monitor_variables = _MON_ANGLE | _MON_VEL | _MON_CURR_Q | _MON_CURR_D| _MON_TARGET;
  motor.monitor_port = &Serial6;
  // initialise magnetic sensors hardware
  sensorAlpha.init();
  // link the motor to the sensorAlpha
  motor.linkSensor(&sensorAlpha);

  // driver config
  // power supply voltage [V]
  driver.voltage_power_supply = 24;
  driver.init();
  // link driver
  motor.linkDriver(&driver);
  // link current sense and the driver
  current_sense.linkDriver(&driver);

  // current sense init hardware
  current_sense.init();
  // link the current sense to the motor
  motor.linkCurrentSense(&current_sense);

  // aligning voltage 
  motor.voltage_sensor_align = 0.9;
  // set motion control loop to be used 
  motor.controller = MotionControlType::torque;
  motor.torque_controller = TorqueControlType::foc_current;
  motor.PID_current_q.P = 0.01;
  motor.PID_current_q.I = 1;
  motor.PID_current_d.P = 0.01; 
  motor.PID_current_d.I = 0.1;
  motor.LPF_current_q.Tf = 0.001f; // 1ms default
  motor.LPF_current_d.Tf = 0.001f; // 1ms default
  motor.LPF_velocity.Tf = 0.02f; 
  motor.LPF_angle.Tf = 0.001f; //These two "preimplemented" filters does not seem to work (I tried them at Tf very long), so we use the LowPassFilter class instead.
  // But it seems to have a difference in the implementation, as the preimplemented filters may affect the Torque loop as well.

  // setting the limits
  //  maximal velocity of the position control
  motor.velocity_limit = 20; // rad/s - default 20


  // default voltage_power_supply
  motor.voltage_limit = 3;

  // initialize motor
  motor.init();
  // align sensorAlpha and start FOC
  motor.initFOC();

  // add target command T
  command.add('T', doTarget, "target voltage");


}

// angle set point variable
float position = 0.0;
int state = 0;
float timemark = millis();
float Serialtimemark = millis();
int counter = 0;

//lookup table
const float Cogging[6284] = {
0, 0, 0, 0, 0, 0, 44.97, 37.76, 33.19, 33.21, 34.74, 36.9, 37.6, 36.98, 37.26, 36.78, 34.7, 30.91, 24.86, 16.73, 9.8, 6.18, 0.42, -5.75, -13.16, -20.34, -29.57, -45.13, -60.96, -76.77, -93.59, -108.83, -122.46, -132.09, -137.49, -143.17, -147.36, -150.19, -149.44, -147.76, -140.64, -132.44, -125.18, -116.35, -104.82, -96.92, -86.79, -80.0, -74.31, -67.52, -61.85, -57.57, -54.11, -50.97, -49.83, -48.45, -49.31, -53.0, -57.3, -61.4, -68.51, -76.95, -85.72, -96.58, -104.2, -112.09, -119.24, -123.85, -129.46, -131.32, -130.01, -131.7, -131.42, -129.59, -127.73, -122.95, -120.17, -117.33, -108.87, -101.16, -92.24, -81.6, -70.17, -57.45, -45.2, -34.87, -26.08, -17.22, -11.61, -6.47, -4.15, -1.97, -2.04, -1.26, -3.69, -5.56, -9.52, -13.75, -18.57, -23.18, -27.97, -34.38, -42.42, -49.7, -57.57, -63.77, -69.88, -76.42, -75.31, -77.45, -76.51, -74.22, -73.01, -69.93, -63.39, -62.94, -56.72, -52.29, -46.6, -40.57, -35.45, -32.88, -28.22, -25.69, -23.79, -21.28, -19.37, -17.86, -16.19, -16.98, -16.82, -16.38, -17.76, -17.04, -17.89, -18.61, -18.17, -17.75, -17.79, -18.42, -20.51, -19.77, -22.13, -19.21, -17.3, -14.32, -8.54, -5.03, -3.17, 1.36, 2.48, 5.17, 6.64, 5.01, 4.68, 5.64, 7.43, 8.36, 8.79, 10.75, 14.15, 16.65, 19.23, 19.69, 21.49, 22.21, 20.48, 18.44, 17.03, 16.1, 16.87, 16.24, 17.26, 21.77, 26.32, 32.05, 38.86, 42.5, 46.64, 51.81, 53.41, 54.81, 55.69, 55.16, 57.3, 59.96, 59.64, 59.34, 58.46, 58.63, 57.37, 53.1, 46.46, 39.55, 34.92, 29.93, 23.37, 16.49, 11.63, 7.61, 5.56, 2.53, -1.26, -3.44, -4.44, -5.39, -4.91, -5.68, -5.0, -1.79, 0.58, 2.31, 6.65, 10.26, 15.11, 17.67, 20.54, 23.37, 26.85, 29.01, 29.76, 29.01, 28.13, 27.64, 24.86, 19.24, 15.36, 10.33, 6.18, 0.29, -8.73, -16.08, -21.69, -30.29, -38.06, -46.46, -50.07, -53.24, -55.69, -57.02, -56.82, -55.0, -50.39, -45.67, -38.0, -29.59, -17.62, -6.5, 6.2, 19.8, 34.04, 47.27, 59.99, 71.19, 83.16, 94.68, 103.9, 109.7, 115.9, 122.77, 125.48, 127.04, 125.36, 123.94, 121.93, 117.82, 110.78, 104.26, 97.72, 92.5, 84.08, 77.88, 71.21, 66.07, 62.66, 58.33, 56.25, 57.0, 56.34, 58.39, 63.07, 65.69, 72.55, 77.99, 84.47, 93.51, 101.66, 108.12, 117.57, 124.41, 131.44, 137.27, 142.49, 145.21, 146.68, 147.87, 147.64, 144.87, 140.0, 133.6, 126.04, 118.32, 107.45, 96.96, 85.45, 74.35, 62.58, 50.57, 40.56, 30.71, 21.28, 12.16, 5.61, -0.17, -2.31, -6.41, -6.73, -7.41, -3.82, -1.49, 2.55, 8.26, 15.6, 22.54, 30.63, 35.53, 42.37, 49.12, 54.65, 58.88, 63.09, 66.01, 69.31, 71.47, 70.86, 69.11, 68.85, 66.53, 63.01, 58.96, 54.3, 49.41, 42.95, 36.08, 29.15, 24.29, 19.81, 15.14, 13.37, 12.87, 11.41, 12.38, 12.28, 13.88, 17.67, 20.3, 23.56, 27.99, 31.0, 37.77, 42.54, 45.86, 49.93, 55.49, 60.17, 63.97, 64.49, 67.31, 71.52, 74.72, 76.05, 78.54, 78.68, 79.64, 78.57, 74.65, 69.77, 63.45, 57.04, 52.41, 46.65, 41.58, 37.1, 32.53, 29.63, 25.42, 22.19, 19.34, 17.52, 14.4, 11.9, 9.76, 10.26, 10.0, 8.65, 7.79, 7.36, 7.7, 8.44, 5.88, 3.65, 2.78, 0.01, -1.79, -6.17, -10.78, -12.69, -14.51, -17.1, -18.33, -19.75, -18.07, -18.23, -18.12, -18.1, -15.74, -12.44, -8.5, -5.67, 0.54, 3.16, 7.43, 10.99, 13.74, 16.65, 19.59, 21.9, 26.22, 28.03, 28.75, 27.88, 27.0, 25.01, 20.31, 14.84, 10.4, 6.11, 2.73, -1.64, -3.83, -5.89, -6.6, -7.45, -8.12, -8.21, -8.67, -10.22, -9.84, -11.46, -10.83, -8.79, -6.71, -2.48, 0.99, 6.12, 12.06, 18.13, 21.2, 24.63, 26.21, 28.89, 27.55, 26.76, 24.05, 21.49, 17.77, 13.72, 8.33, 1.74, -5.31, -11.01, -17.87, -26.05, -33.77, -43.14, -52.68, -62.46, -73.85, -83.29, -95.98, -106.42, -113.72, -119.69, -124.0, -127.37, -129.24, -125.29, -119.87, -113.2, -104.59, -95.3, -85.99, -74.66, -66.11, -58.33, -51.86, -46.44, -41.67, -39.07, -39.71, -38.89, -41.09, -43.46, -44.39, -49.94, -53.58, -59.36, -66.14, -73.67, -83.04, -94.41, -104.6, -115.97, -125.44, -133.94, -141.58, -148.37, -150.9, -150.82, -151.29, -150.95, -145.22, -141.19, -135.07, -129.23, -122.31, -112.29, -100.62, -92.21, -79.64, -66.48, -54.94, -44.59, -34.51, -25.64, -18.22, -12.19, -8.1, -5.7, -5.36, -6.97, -10.89, -15.56, -23.03, -31.06, -39.57, -47.17, -56.73, -65.62, -75.97, -85.95, -94.11, -102.41, -110.4, -115.49, -119.91, -122.04, -119.45, -118.25, -113.25, -106.4, -98.47, -90.92, -81.45, -73.62, -65.59, -57.46, -51.71, -46.77, -39.26, -33.86, -30.08, -26.15, -25.75, -23.43, -23.49, -25.29, -28.89, -31.75, -34.75, -38.34, -43.24, -47.86, -52.34, -56.21, -62.1, -69.36, -75.67, -83.98, -90.16, -96.03, -95.01, -91.1, -90.1, -83.81, -74.7, -66.47, -58.98, -56.36, -55.24, -50.13, -51.23, -51.82, -50.91, -48.92, -46.39, -41.62, -36.6, -30.74, -24.96, -19.3, -14.68, -11.84, -12.46, -13.47, -13.74, -14.99, -18.76, -20.01, -20.3, -18.72, -16.13, -11.67, -6.79, 1.79, 5.44, 10.48, 14.66, 15.19, 14.54, 11.3, 7.01, 3.68, -1.13, -3.64, -2.43, -2.0, 0.6, 1.44, 3.81, 5.52, 5.29, 4.34, 3.5, 3.27, 3.85, 4.61, 4.54, 5.3, 5.53, 6.56, 6.46, 5.54, 4.98, 4.49, 4.81, 5.36, 5.2, 5.98, 7.94, 8.43, 11.9, 12.55, 13.13, 15.13, 15.69, 15.31, 16.47, 14.2, 13.18, 13.04, 9.19, 6.36, 4.4, -0.97, -4.43, -9.65, -15.63, -19.87, -25.39, -32.45, -34.26, -38.37, -41.29, -41.96, -43.06, -40.78, -37.43, -35.6, -32.71, -26.99, -21.77, -12.58, -5.53, 3.49, 13.71, 24.81, 36.42, 47.29, 57.07, 67.71, 77.75, 84.82, 91.45, 95.69, 99.2, 101.44, 102.02, 101.92, 100.58, 98.56, 96.24, 94.2, 90.18, 85.14, 79.29, 74.51, 70.74, 66.26, 61.99, 57.54, 56.96, 56.03, 56.72, 57.52, 60.44, 62.92, 68.99, 74.1, 81.72, 88.12, 96.5, 103.18, 110.8, 117.88, 125.76, 129.0, 133.48, 136.55, 139.52, 142.03, 141.36, 139.51, 138.72, 135.33, 130.18, 122.93, 110.74, 100.0, 86.76, 71.26, 57.49, 44.14, 30.72, 20.06, 11.49, 1.64, -2.78, -8.27, -12.56, -16.94, -18.64, -21.13, -19.07, -18.95, -15.86, -10.43, -0.61, 9.99, 20.43, 30.48, 42.99, 54.51, 64.66, 72.91, 80.08, 87.08, 93.6, 96.98, 101.02, 101.77, 101.31, 100.16, 96.12, 91.98, 88.12, 81.48, 72.47, 66.53, 58.45, 52.78, 45.78, 38.05, 32.56, 31.47, 27.92, 28.22, 28.44, 30.31, 34.36, 39.48, 45.68, 52.65, 61.49, 69.24, 77.94, 88.63, 96.55, 104.83, 115.2, 121.68, 128.49, 136.68, 141.53, 147.09, 152.16, 154.72, 157.16, 158.99, 157.85, 155.64, 151.86, 145.36, 138.26, 130.13, 121.91, 109.31, 100.15, 90.65, 81.5, 72.91, 66.58, 59.79, 57.72, 54.56, 50.78, 48.44, 47.06, 44.0, 44.45, 43.41, 43.22, 46.73, 47.7, 49.59, 53.71, 55.95, 58.23, 57.76, 57.23, 57.74, 56.2, 52.48, 49.29, 44.7, 43.19, 38.77, 34.09, 30.04, 25.92, 21.59, 18.38, 13.39, 11.35, 9.58, 7.64, 6.22, 4.61, 4.63, 4.17, 2.42, 1.28, 1.25, 1.71, 2.77, 3.0, 3.01, 3.74, 5.87, 7.16, 7.24, 6.45, 5.38, 4.58, 3.21, 1.28, 0.44, 2.65, 3.26, 4.63, 5.59, 7.65, 8.81, 7.8, 4.83, 3.66, 2.65, 2.54, 0.33, -0.77, 0.23, 1.79, 4.59, 6.25, 7.55, 9.93, 12.45, 12.56, 12.96, 11.79, 10.79, 7.64, 4.42, -0.77, -3.39, -5.48, -8.84, -10.96, -11.02, -13.37, -14.53, -17.66, -24.08, -31.05, -40.34, -50.69, -58.16, -64.53, -74.59, -79.38, -81.32, -82.3, -80.05, -77.17, -75.89, -67.85, -62.55, -56.53, -49.29, -42.38, -36.06, -30.16, -25.65, -21.96, -19.99, -19.06, -19.61, -22.51, -24.79, -30.19, -36.89, -43.16, -47.72, -55.65, -63.73, -73.69, -81.89, -90.61, -101.28, -112.27, -122.23, -129.35, -134.9, -141.23, -147.44, -147.11, -146.79, -142.01, -137.59, -130.81, -122.4, -111.93, -101.85, -93.16, -86.18, -76.37, -66.35, -56.96, -44.05, -36.8, -27.5, -19.84, -15.52, -11.07, -8.78, -10.98, -12.21, -16.84, -21.12, -26.62, -34.85, -41.74, -49.49, -59.37, -66.48, -73.66, -79.3, -87.19, -94.54, -100.53, -104.84, -109.47, -113.23, -115.87, -116.06, -115.27, -108.92, -103.75, -96.7, -88.28, -79.35, -69.77, -58.46, -50.96, -42.38, -33.51, -26.83, -21.94, -16.56, -13.75, -13.66, -13.58, -17.39, -20.67, -26.42, -33.55, -42.94, -51.44, -61.59, -69.86, -80.63, -91.46, -102.31, -111.78, -122.86, -130.27, -141.96, -151.66, -158.32, -165.87, -169.22, -167.91, -168.6, -163.08, -156.33, -148.53, -139.3, -130.97, -125.15, -116.77, -112.15, -106.53, -103.18, -97.22, -93.55, -87.47, -82.95, -76.38, -71.59, -66.57, -63.95, -61.4, -61.51, -62.78, -66.03, -69.46, -71.96, -75.08, -76.75, -78.33, -78.22, -77.46, -74.76, -73.72, -70.78, -67.79, -65.54, -62.99, -61.44, -59.25, -56.17, -54.25, -52.47, -47.63, -43.17, -37.13, -31.71, -25.75, -19.16, -14.58, -8.96, -4.19, 1.64, 4.63, 7.81, 10.67, 14.08, 14.52, 14.52, 12.49, 12.4, 11.0, 9.01, 7.73, 4.48, 3.34, 2.02, 0.57, -0.44, -1.23, -3.28, -3.06, -4.11, -3.37, -3.67, -3.68, -2.75, -0.56, -0.43, 1.62, 2.19, 3.52, 4.26, 3.61, 1.81, 1.63, -0.61, -1.41, -2.47, -2.96, -3.91, -4.56, -5.32, -5.05, -5.16, -6.32, -6.04, -4.98, -1.13, 2.65, 6.45, 9.56, 14.23, 20.34, 26.27, 30.62, 36.37, 41.5, 49.44, 55.69, 61.72, 66.57, 70.95, 75.34, 77.97, 76.91, 78.3, 76.86, 76.16, 74.74, 72.7, 71.12, 70.47, 67.36, 64.12, 61.92, 59.97, 57.21, 55.14, 53.09, 52.53, 52.32, 51.81, 53.31, 53.88, 56.93, 59.87, 64.85, 70.9, 75.93, 79.76, 85.98, 90.58, 95.18, 99.78, 102.39, 107.16, 111.7, 113.49, 115.38, 115.97, 114.26, 112.67, 107.33, 99.08, 90.9, 79.39, 69.81, 58.15, 47.53, 35.19, 24.44, 15.41, 7.25, -1.91, -7.8, -16.15, -18.67, -21.53, -23.63, -22.13, -21.27, -20.04, -15.09, -10.17, -2.17, 6.62, 15.68, 27.52, 38.66, 47.2, 57.62, 67.18, 74.47, 82.24, 88.46, 93.42, 99.56, 102.8, 103.84, 106.54, 106.79, 107.46, 103.84, 98.29, 93.26, 86.54, 78.31, 69.13, 57.55, 51.34, 46.62, 39.98, 37.0, 34.89, 33.61, 35.95, 37.9, 43.41, 49.57, 55.55, 62.01, 70.11, 78.77, 89.06, 98.54, 109.87, 121.57, 133.38, 144.42, 155.81, 165.36, 174.01, 178.39, 183.86, 187.53, 189.64, 187.75, 184.93, 177.9, 171.91, 162.65, 153.1, 145.74, 136.85, 125.62, 117.22, 108.7, 101.37, 92.26, 81.56, 72.84, 67.17, 62.51, 58.58, 54.93, 53.57, 54.06, 56.28, 60.11, 61.93, 64.35, 67.82, 72.74, 75.53, 77.99, 81.45, 84.58, 89.36, 92.2, 93.03, 96.22, 98.44, 95.89, 93.09, 90.03, 86.2, 81.88, 71.74, 62.6, 54.28, 47.5, 38.09, 30.34, 22.52, 17.21, 11.59, 6.91, 1.82, -1.53, -5.23, -6.09, -6.46, -7.42, -7.08, -6.06, -4.83, -2.96, -2.02, -0.11, 3.77, 7.35, 9.29, 11.6, 13.68, 15.8, 17.79, 18.33, 18.2, 20.01, 20.33, 21.06, 20.62, 18.98, 16.97, 14.57, 10.53, 8.85, 4.76, 1.73, 1.74, 0.8, 1.84, 1.54, 1.64, 3.15, 4.94, 3.79, 5.71, 3.06, 4.07, 3.86, 2.99, 1.72, 2.08, 1.26, 1.94, 2.45, 1.51, 4.24, 3.07, 1.85, -1.5, -3.7, -7.93, -9.79, -14.55, -15.62, -17.46, -21.64, -24.57, -26.37, -28.74, -32.93, -34.85, -34.81, -31.11, -29.11, -26.93, -24.84, -21.19, -18.77, -19.24, -19.8, -20.83, -19.88, -21.43, -21.84, -26.16, -26.26, -28.42, -30.14, -35.58, -38.99, -43.54, -49.45, -59.18, -67.98, -76.18, -82.41, -90.24, -98.08, -103.66, -109.7, -114.9, -115.48, -121.55, -124.62, -123.74, -124.82, -123.01, -117.62, -118.0, -108.91, -101.89, -96.57, -84.18, -73.67, -64.96, -52.62, -44.74, -35.93, -30.14, -25.69, -21.11, -18.71, -18.12, -18.34, -17.91, -18.75, -22.06, -26.3, -28.65, -32.8, -39.12, -47.79, -54.72, -66.25, -74.23, -81.36, -88.78, -94.3, -97.65, -101.97, -99.09, -100.13, -98.41, -94.29, -89.16, -85.23, -77.91, -69.31, -61.44, -55.43, -50.18, -41.71, -32.87, -25.47, -19.75, -12.63, -8.39, -2.83, -1.35, -3.59, -6.05, -11.85, -17.16, -24.67, -34.56, -46.82, -54.97, -66.08, -77.42, -91.85, -103.1, -117.35, -129.54, -144.03, -158.58, -167.87, -175.39, -185.39, -188.75, -193.34, -195.56, -191.62, -191.2, -186.47, -181.23, -178.14, -169.81, -161.65, -154.94, -148.25, -142.06, -133.47, -124.18, -115.63, -109.13, -103.72, -97.35, -94.46, -91.38, -90.45, -92.35, -90.95, -92.62, -95.58, -95.67, -98.15, -99.86, -101.13, -104.85, -104.99, -106.86, -108.28, -110.38, -111.58, -111.85, -111.11, -114.02, -110.19, -106.2, -102.6, -95.68, -86.9, -79.59, -66.73, -56.65, -48.48, -37.31, -28.17, -20.08, -9.17, -1.21, 5.19, 12.99, 19.85, 24.6, 28.36, 29.54, 31.15, 31.09, 29.23, 27.65, 24.73, 19.83, 16.01, 10.87, 5.99, 2.94, -0.91, -4.51, -5.13, -8.97, -10.44, -12.08, -14.78, -17.08, -17.12, -18.06, -13.43, -12.73, -8.98, -5.21, -3.57, 0.25, 3.52, 4.96, 6.65, 8.35, 7.93, 11.64, 12.24, 11.9, 12.89, 14.19, 15.89, 15.74, 13.72, 12.63, 9.93, 5.22, 2.61, -1.25, -2.55, -4.57, -3.68, -2.27, 0.28, 3.95, 1.84, 4.85, 7.61, 7.77, 10.28, 11.15, 10.73, 14.73, 14.45, 17.7, 18.29, 18.69, 24.64, 26.57, 27.25, 28.41, 26.46, 25.21, 26.23, 18.09, 14.58, 15.02, 14.76, 14.99, 17.31, 16.35, 20.54, 22.94, 24.27, 27.15, 30.62, 33.26, 37.02, 39.91, 44.67, 50.59, 54.03, 59.28, 63.02, 66.75, 69.49, 73.6, 73.97, 75.78, 76.63, 76.94, 76.75, 74.17, 69.32, 64.75, 60.39, 53.33, 46.23, 40.25, 34.14, 29.38, 23.55, 17.3, 11.06, 6.72, 1.67, 0.48, -2.38, -2.96, -1.33, -0.41, 1.7, 7.56, 13.16, 20.89, 29.16, 36.87, 48.3, 59.03, 66.43, 75.67, 85.02, 93.25, 100.38, 106.03, 113.14, 119.24, 121.6, 121.3, 122.11, 123.15, 123.32, 119.36, 114.29, 108.36, 103.62, 95.7, 87.62, 78.29, 72.14, 64.5, 60.22, 55.38, 53.87, 51.07, 50.69, 49.17, 50.57, 53.61, 57.64, 60.7, 68.22, 74.77, 84.91, 95.07, 104.5, 118.2, 134.17, 143.24, 153.33, 160.48, 171.04, 179.41, 181.28, 183.97, 186.81, 187.94, 187.7, 182.39, 179.37, 173.72, 163.9, 157.15, 149.87, 140.83, 130.79, 118.73, 108.79, 99.27, 90.5, 81.85, 74.31, 69.21, 64.14, 62.6, 62.33, 60.35, 60.17, 62.61, 66.24, 71.19, 76.34, 80.45, 86.14, 94.66, 103.76, 109.16, 115.02, 116.31, 120.84, 123.2, 123.18, 120.69, 119.09, 114.36, 112.98, 106.08, 100.45, 93.2, 85.29, 77.08, 67.92, 55.92, 46.55, 39.26, 31.34, 22.81, 15.2, 10.39, 6.07, 2.43, -2.52, -5.29, -7.61, -8.3, -9.75, -6.59, -3.11, -1.81, 1.83, 6.61, 10.6, 16.13, 17.54, 18.29, 22.89, 24.39, 25.38, 26.0, 24.87, 24.67, 24.65, 20.98, 17.94, 15.85, 12.93, 11.25, 7.6, 2.3, -1.07, -4.53, -9.83, -13.56, -17.3, -19.4, -20.47, -20.47, -20.73, -19.9, -16.65, -14.99, -12.89, -8.8, -6.06, -2.5, -0.34, 0.52, 5.24, 9.81, 12.41, 15.27, 15.63, 18.51, 20.16, 18.66, 19.23, 19.37, 16.94, 16.4, 13.77, 14.98, 15.62, 10.85, 10.26, 10.18, 8.23, 9.19, 5.44, 3.87, 4.77, 1.3, -0.06, 0.79, 0.9, 0.92, -0.48, -1.17, 0.2, -1.47, -4.08, -7.17, -9.6, -11.39, -14.08, -19.95, -24.01, -26.73, -32.19, -34.55, -37.4, -40.51, -38.16, -40.62, -46.51, -47.52, -52.68, -56.57, -59.36, -65.75, -66.72, -63.55, -64.02, -61.06, -56.5, -52.69, -47.81, -41.04, -36.71, -30.08, -24.87, -20.93, -16.17, -10.52, -7.52, -3.58, -0.47, 0.63, 1.14, 1.91, 0.43, -1.74, -5.03, -8.38, -12.17, -19.67, -25.73, -34.47, -43.32, -50.72, -57.69, -64.7, -69.08, -74.09, -77.58, -79.85, -80.39, -80.33, -79.19, -77.69, -76.66, -70.33, -63.43, -59.29, -55.14, -49.46, -43.87, -38.06, -35.48, -32.81, -28.76, -25.75, -24.19, -23.71, -25.42, -27.57, -31.02, -36.91, -44.92, -53.75, -63.32, -74.13, -86.31, -98.64, -109.98, -122.54, -136.89, -151.74, -166.63, -178.84, -190.76, -203.65, -212.65, -218.68, -224.6, -225.69, -227.99, -227.78, -221.99, -219.55, -213.63, -203.27, -193.29, -181.57, -171.21, -164.41, -154.04, -144.83, -138.86, -132.91, -126.72, -121.51, -117.19, -113.37, -111.82, -109.73, -105.5, -105.51, -106.78, -109.62, -110.83, -112.0, -111.38, -117.94, -123.81, -128.47, -127.52, -131.71, -132.68, -136.65, -134.79, -131.29, -126.52, -122.1, -115.15, -105.2, -96.66, -87.17, -75.28, -58.65, -48.06, -34.19, -24.97, -10.36, 1.68, 12.72, 18.49, 27.74, 33.54, 38.5, 40.91, 41.44, 40.92, 39.23, 37.02, 32.82, 28.9, 23.37, 20.36, 15.63, 11.88, 6.02, 3.9, -1.36, -5.3, -10.1, -14.96, -19.75, -20.63, -22.74, -22.24, -22.1, -20.49, -16.12, -13.27, -10.08, -5.99, -0.73, 4.31, 9.05, 14.19, 20.28, 22.24, 23.49, 21.66, 22.5, 21.46, 19.51, 16.07, 17.47, 16.72, 15.58, 11.67, 7.69, 0.81, -4.48, -13.02, -18.59, -22.62, -25.55, -28.88, -28.36, -28.78, -28.61, -28.73, -28.93, -31.24, -30.72, -31.92, -33.09, -32.41, -30.72, -29.15, -24.62, -20.94, -18.07, -10.9, -8.36, -6.01, -4.99, -4.77, -4.21, -1.56, -2.9, -0.2, 0.84, 4.95, 7.12, 7.71, 8.24, 7.97, 6.0, 5.01, 5.28, 5.15, 5.6, 6.37, 11.07, 14.07, 17.14, 17.04, 20.06, 25.42, 26.19, 27.29, 30.52, 31.8, 33.66, 35.68, 37.89, 37.16, 34.67, 32.77, 30.38, 28.58, 26.2, 19.22, 21.47, 19.32, 16.34, 13.91, 13.89, 12.29, 12.04, 9.59, 9.33, 10.84, 13.28, 13.45, 17.28, 21.34, 24.06, 29.83, 35.35, 43.34, 50.0, 54.66, 60.81, 68.29, 73.57, 79.84, 82.93, 86.54, 87.92, 88.32, 85.38, 83.9, 79.78, 75.85, 72.33, 67.94, 62.0, 58.98, 57.36, 52.47, 46.31, 41.8, 37.95, 36.12, 32.95, 28.22, 27.07, 29.94, 31.35, 34.36, 38.15, 44.45, 51.24, 59.59, 68.0, 76.48, 86.29, 98.42, 109.66, 119.73, 130.2, 139.43, 148.03, 156.88, 161.73, 165.75, 167.81, 168.81, 168.01, 166.55, 165.1, 159.73, 153.49, 147.87, 140.36, 133.07, 125.75, 115.58, 110.63, 102.37, 97.75, 93.72, 89.15, 85.13, 83.13, 80.76, 84.94, 84.91, 88.09, 90.08, 96.78, 102.7, 109.19, 114.89, 123.25, 127.96, 137.02, 143.48, 148.37, 154.16, 156.38, 158.49, 161.22, 161.63, 158.51, 157.56, 150.24, 143.04, 134.32, 124.7, 114.0, 103.02, 90.58, 78.43, 69.36, 57.33, 47.59, 37.55, 27.8, 19.41, 12.8, 5.66, -1.61, -6.27, -9.43, -9.59, -10.2, -8.21, -6.16, 0.5, 4.35, 8.89, 12.63, 16.55, 19.81, 24.04, 25.73, 26.34, 26.99, 27.07, 26.75, 24.78, 21.43, 17.11, 11.88, 4.33, -3.4, -11.69, -17.47, -25.54, -34.45, -41.19, -46.37, -51.02, -54.7, -57.57, -59.79, -56.59, -53.88, -50.33, -44.49, -37.57, -31.8, -24.93, -17.54, -9.73, 0.69, 6.88, 14.54, 21.29, 30.06, 37.13, 44.54, 48.17, 53.63, 57.27, 64.84, 63.78, 62.92, 61.69, 60.11, 59.84, 57.99, 52.73, 53.36, 50.88, 48.44, 46.77, 43.69, 39.91, 36.11, 32.43, 30.19, 27.12, 23.63, 21.03, 20.02, 19.21, 20.56, 21.7, 21.48, 23.27, 23.18, 20.53, 24.48, 19.28, 19.15, 19.96, 18.66, 18.59, 19.74, 14.47, 16.54, 13.91, 12.39, 10.68, 8.52, 8.03, 6.11, 5.29, 4.14, 1.5, -1.49, -1.72, -2.94, -3.33, -4.06, -3.84, -1.62, 2.08, 4.14, 5.88, 8.84, 10.36, 10.93, 8.98, 7.28, 4.71, 5.12, 1.66, 1.15, 0.59, -0.82, -5.16, -7.75, -14.71,
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
void loop() {
  counter++;
  motor.loopFOC();
  motor.move(target_current);

  //read position sensor alpha
  position = sensorAlpha.getAngle();

  //convert it to 0-2PI milliradians
  position = fmod(position, 2*PI);
  if (position < 0) {
    position += 2*PI;
  }
  position = uint16_t(position*1000);

  //print the cogging value
  if (millis() - Serialtimemark > 100) {
    Serialtimemark = millis();
    Serial6.print("position:");
    Serial6.println(position);
    Serial6.println(getCogValue(position)/1000);
    Serial6.println(state);
    //Serial6.println(2*counter);
    //counter = 0;
  }
  
  //changing parameter value depending on time
  if (millis() - timemark > 5000) {
    timemark = millis();
    //state = (state + 1) % 2;
  }

  switch (state) {
    case 0:
      target_current = getCogValue(position)/1000;
      break;
    case 1:
      target_current = 0*getCogValue(position)/1000;
      break;
    default:
      // Handle unexpected cases
      break;
  }
}

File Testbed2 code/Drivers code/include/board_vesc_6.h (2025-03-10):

#include <Arduino.h>

void SystemClock_Config(void)
{
  RCC_OscInitTypeDef RCC_OscInitStruct = {0};
  RCC_ClkInitTypeDef RCC_ClkInitStruct = {0};

  /** Configure the main internal regulator output voltage
  */
  __HAL_RCC_PWR_CLK_ENABLE();
  __HAL_PWR_VOLTAGESCALING_CONFIG(PWR_REGULATOR_VOLTAGE_SCALE1);
  /** Initializes the RCC Oscillators according to the specified parameters
  * in the RCC_OscInitTypeDef structure.
  */
  RCC_OscInitStruct.OscillatorType = RCC_OSCILLATORTYPE_HSE;
  RCC_OscInitStruct.HSEState = RCC_HSE_ON;
  RCC_OscInitStruct.PLL.PLLState = RCC_PLL_ON;
  RCC_OscInitStruct.PLL.PLLSource = RCC_PLLSOURCE_HSE;
  RCC_OscInitStruct.PLL.PLLM = 8;
  RCC_OscInitStruct.PLL.PLLN = 336;
  RCC_OscInitStruct.PLL.PLLP = RCC_PLLP_DIV2;
  RCC_OscInitStruct.PLL.PLLQ = 7;
  if (HAL_RCC_OscConfig(&RCC_OscInitStruct) != HAL_OK)
  {
    Error_Handler();
  }
  /** Initializes the CPU, AHB and APB buses clocks
  */
  RCC_ClkInitStruct.ClockType = RCC_CLOCKTYPE_HCLK|RCC_CLOCKTYPE_SYSCLK
                              |RCC_CLOCKTYPE_PCLK1|RCC_CLOCKTYPE_PCLK2;
  RCC_ClkInitStruct.SYSCLKSource = RCC_SYSCLKSOURCE_PLLCLK;
  RCC_ClkInitStruct.AHBCLKDivider = RCC_SYSCLK_DIV1;
  RCC_ClkInitStruct.APB1CLKDivider = RCC_HCLK_DIV4;
  RCC_ClkInitStruct.APB2CLKDivider = RCC_HCLK_DIV2;

  if (HAL_RCC_ClockConfig(&RCC_ClkInitStruct, FLASH_LATENCY_5) != HAL_OK)
  {
    Error_Handler();
  }
}


// PORT #1:  CAN  
// =============
#define CAN_RX        PB8
#define CAN_TX        PB9

// PORT #2: HALL, ENCODER, I2C1 or USART6
// ======================================
#define HALL_1        PC6
#define HALL_2        PC7
#define HALL_3        PC8
// OR
#define ENC_A         PC6
#define ENC_B         PC7
#define ENC_I         PC8
// OR
#define USART6_TX    PC6
#define USART6_RX    PC7
// AND
#define TEMP_MOTOR    PC4

// PORT #3: USART3, I2C2 or SPI1
// =============================
#define USART3_TX     PB10
#define USART3_RX     PB11
// OR
#define I2C2_SCL      PB10
#define I2C2_SDA      PB11
// OR
#define SPI1_NSS      PA4
#define SPI1_SCLK     PA5                    
#define SPI1_MISO     PA6
#define SPI1_MOSI     PA7
#define SPI1_NSS_2    PC5

// PORT #4: SWD
// ============
#define SWDIO         PA13
#define SWCLK         PA14

// PORT #5: SERVO
// ==============
#define SERVO         PB6

// PORT #6: USB
// ============
#define USB_DM        PA11
#define USB_DP        PA12

// #7: INTERNAL PINS
// =================
#define VOLTAGE_1     PA0
#define VOLTAGE_2     PA1
#define VOLTAGE_3     PA2
#define ADC_TEMP      PA3
#define H1            PA8
#define H2            PA9
#define H3            PA10
#define CURRENT_1     PC0
#define CURRENT_2     PC1
#define CURRENT_3     PC2
#define L1            PB13
#define L2            PB14
#define L3            PB15
#define AN_IN         PC3
#define LED_GREEN     PB0
#define LED_RED       PB1
#define EN_GATE       PB5
#define FAULT         PB7
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

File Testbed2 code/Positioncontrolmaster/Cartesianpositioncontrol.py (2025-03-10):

#region import libraries #
import numpy as np
import time
import matplotlib.pyplot as plt
from matplotlib.patches import Arc
from Simplyserial import serconnect,sersendfloat, listports

# endregion

# region init serial #

try:
    print(listports())
    ser = serconnect()
except:
    print("Error: Could not connect to serial port.")
    pass

# endregion

# region geometric parameters 
motor_pulley_d = 0.026
Arm_pulley_D = [0.114, 0.06, 0.042]
L = [0.209,0.159,0.085]  # Length of the arm joints

# theta to alpha matrix
inverse_kinematics_matrix = 1/motor_pulley_d * np.array([[ Arm_pulley_D[0], Arm_pulley_D[1],  Arm_pulley_D[2]],
                                                         [ Arm_pulley_D[0],  -Arm_pulley_D[1], -Arm_pulley_D[2]],
                                                         [-Arm_pulley_D[0],  Arm_pulley_D[1],  0              ],
                                                         [-Arm_pulley_D[0], -Arm_pulley_D[1],  0              ]])
# Function to calculate the angles of the motors based on the desired angles of the arm joints
def theta_to_alpha(theta):
    alpha = np.dot(inverse_kinematics_matrix, theta)
    return alpha

#position variables
xy = [0.367,0]
theta = [0,0,0]
alpha = [0,0,0,0]

# endregion

# region plot functions
# Function to calculate the positions of the arm parts
def calculate_positions(theta):
    x0, y0 = 0, 0
    x1 = L[0] * np.cos(theta[0])
    y1 = L[0] * np.sin(theta[0])
    x2 = x1 + L[1] * np.cos(theta[0] + theta[1])
    y2 = y1 + L[1] * np.sin(theta[0] + theta[1])
    x3 = x2 + L[2] * np.cos(theta[0] + theta[1] + theta[2])
    y3 = y2 + L[2] * np.sin(theta[0] + theta[1] + theta[2])
    return [(x0, y0), (x1, y1), (x2, y2), (x3, y3)]

# Function to plot the reach of the arm
def armreachplot(fig,ax):
    arc1 = Arc((0,0),2*0.204767,2*0.204767,angle=0,theta1=-82.413,theta2=82.413, color='r', linewidth=2)
    arc2 = Arc((0,0),2*0.368,2*0.368,angle=0,theta1=-37.23,theta2=37.23, color='r', linewidth=2)
    arc3 = Arc((0.166409,0.126448),2*0.159,2*0.159,angle=0,theta1=37.23,theta2=151.23, color='r', linewidth=2)
    arc4 = Arc((0.166409,-0.126448),2*0.159,2*0.159,angle=0,theta1=-151.23,theta2=-37.23, color='r', linewidth=2)
    ax.add_patch(arc1)
    ax.add_patch(arc2)
    ax.add_patch(arc3)
    ax.add_patch(arc4)
    #plot a line between (0.209,0) and (0.209+0.159,0)
    ax.plot([0.2047,0.2047+0.159],[0,0],'r')
    return fig,ax
# endregion

# Function to calculate inverse kinematics based on just 2 joints, third one will serve for sensing purposes
def inverse_kinematics(x, y):
    #kinematics: j'ai x = L[0]*cos(theta[0]) + L[1]*cos(theta[0]+theta[1])
    #            j'ai y = L[0]*sin(theta[0]) + L[1]*sin(theta[0]+theta[1])

    # Calculate distance d
    d = np.sqrt(x**2 + y**2)

    # Calculate angle psi
    psi = np.arctan2(y, x)

    # Use the law of cosines to find theta1
    cos_theta1 = (L[0]**2 + L[1]**2 - d**2) / (2 * L[0] * L[1])
    cos_theta1 = np.clip(cos_theta1, -1.0, 1.0)  # Ensure the value is within [-1, 1] for arccos
    theta1_elbow_up = np.pi - np.arccos(cos_theta1)
    theta1_elbow_down = np.arccos(cos_theta1)-np.pi

    # Find theta0 for both configurations
    theta0_elbow_up = psi - np.arctan2(L[1] * np.sin(theta1_elbow_up), L[0] + L[1] * np.cos(theta1_elbow_up))
    theta0_elbow_down = psi - np.arctan2(L[1] * np.sin(theta1_elbow_down), L[0] + L[1] * np.cos(theta1_elbow_down))

    # Choose solution based on the sign of
    if y >= 0:
        theta[0] = theta0_elbow_up
        theta[1] = theta1_elbow_up
    else:
        theta[0] = theta0_elbow_down
        theta[1] = theta1_elbow_down

    #check if thetas are within the limits
    if theta[0] < -37.23*np.pi/180:
        print("Theta 0 is out of reach")
        theta[0]=-37.23*np.pi/180
    elif theta[0] > 37.23*np.pi/180:
        print("Theta 0 is out of reach")
        theta[0]=37.23*np.pi/180
    if theta[1] < -114*np.pi/180:
        print("Theta 1 is out of reach")
        theta[1]=-114*np.pi/180
    elif theta[1] > 114*np.pi/180:
        print("Theta 1 is out of reach")
        theta[1]=114*np.pi/180
    return theta

#function to plot 10 waypoints between two position (previous and next)
def waypoints(previous, next):
    if np.sign(previous[1]) == np.sign(next[1]):
        distance = np.sqrt((next[0] - previous[0])**2 + (next[1] - previous[1])**2)
        num_points = int(distance / 0.01)
        x = np.linspace(previous[0], next[0], num_points)
        y = np.linspace(previous[1], next[1], num_points)
    else:
        distance1 = np.sqrt((0.3637 - previous[0])**2 + (0 - previous[1])**2)
        distance2 = np.sqrt((next[0] - 0.3637)**2 + (next[1] - 0)**2)
        num_points1 = int(distance1 / 0.01)
        num_points2 = int(distance2 / 0.01)
        x1 = np.linspace(previous[0], 0.3637, num_points1)
        y1 = np.linspace(previous[1], 0, num_points1)
        x2 = np.linspace(0.3637, next[0], num_points2)
        y2 = np.linspace(0, next[1], num_points2)
        x = np.concatenate((x1, x2))
        y = np.concatenate((y1, y2))
    ax.plot(x, y, 'bx')
    fig.canvas.draw_idle()
    return x, y

# region click and button events
def onclick(event):
    global xy
    x = event.xdata
    y = event.ydata
    theta = inverse_kinematics(x, y)
    positions = calculate_positions(theta)
    for i in range(2):
        lines[i].set_data([positions[i][0], positions[i+1][0]], [positions[i][1], positions[i+1][1]])
    xlist,ylist = waypoints(xy,[x,y])
    #here you will use xlist ylist to convert it to a list of theta angle and then send them over a certain duration 
    for i in range(len(xlist)):
        plt.plot(xlist[i], ylist[i], 'bx')
        theta = inverse_kinematics(xlist[i], ylist[i])
        try:
            sersendfloat(-theta[0],ser)
            sersendfloat(-theta[1],ser)
            sersendfloat(-theta[2],ser)
            print(f'{theta[0]},{theta[1]},{theta[2]}')
            time.sleep(0.2)
        except:
            #print(f'{theta[0]},{theta[1]},{theta[2]}')
            pass
    xy = [x,y]
    #for i in range(60):
    #    theta[2] = 1*np.sin(2 * np.pi * i / 20)
    #    try:
    #        sersendfloat(-theta[0],ser)
    #        sersendfloat(-2*theta[1],ser)
    #        sersendfloat(-theta[2],ser)
    #        time.sleep(0.05)
    #    except:
    #        pass


def onpress1(event):
    sersendfloat(50.0,ser)

def onpress2(event):
    global xy
    xy = [0.367,0]
    sersendfloat(51.0,ser)
# endregion

# region plot setup
fig, ax = plt.subplots()
ax.set_ylim(-0.4, 0.4)
ax.set_xlim(-0.2, 0.5)
ax.set_aspect('equal')

#add two buttons to the plot in the bottom right
#axbutton1 = plt.axes([0.7, 0.05, 0.1, 0.075])
#axbutton2 = plt.axes([0.81, 0.05, 0.1, 0.075])
#button1 = Button(axbutton1, 'compliant')
#button2 = Button(axbutton2, 'stiff')
#button1.on_clicked(onpress1)
#button2.on_clicked(onpress2)
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
